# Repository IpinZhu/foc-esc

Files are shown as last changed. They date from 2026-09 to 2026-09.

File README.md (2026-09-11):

# STM32G473 三相 FOC 驱动器

这是一个基于 STM32G473RC 的实验性三相 PMSM/BLDC 电机控制平台。仓库包含驱动板设计，以及使用 Rust 2024 + Embassy 实现的电流控制型磁场定向控制（FOC）固件。

> **安全提示：** 这是一个大电流电力电子原型。固件和 PCB 尚未完成生产级电气鉴定或验证。在使用合适的实验设备和限流措施检查栅极波形、死区时间、电流采样极性、ADC 时序、故障响应、绝缘/间距和热性能之前，不要连接电机或电池。

## 当前实现

当前固件位于 [`software/firmware`](software/firmware)，目标芯片为 STM32G473RC：

- TIM1 中心对齐互补 PWM，输出引脚为 PA8/PA9/PA10 和 PB13/PB14/PB15。
- 配置的 PWM 频率：**100 kHz**。
- 配置的死区时间：在 170 MHz 定时器时钟下为 **200 ns**。
- 占空比范围：5%–95%。
- 通过 INA240A2 放大器和 0.5 mΩ 分流电阻进行三相电流反馈。
- 由定时器触发 ADC，对相电流、VBUS 和 TMP235 温度传感器进行采样。
- 支持电流 FOC、速度 FOC、开环控制、启动电流偏置校准、SVPWM、遥测和软件故障处理。
- 带版本和 CRC 的双槽 Flash 参数持久化：上电自动加载，UART `param ...` 命令和 CAN 参数帧可读取、设置、保存或恢复出厂参数。
- 电机参数自整定（Auto-Tune）：`autotune start` 一键完成 Rs/L/磁链辨识、电流环 PI 计算与阶跃验证、开环同步校验和观测器参数配置，结果保存为带 CRC 的电机参数档案，重启后自动应用。
- 编译期选择转子传感器：
  - `sensor-encoder`（默认）：TIM3 正交编码器，连接 PB4/PB5。
  - `sensor-hall`：TIM3 Hall 输入捕获，连接 PC6/PC7/PC8。
- USART3 ASCII 调试命令，连接 PB10/PB11。
- FDCAN1 classic CAN 控制和遥测，连接 PA11/PA12。

当前固件采用**纯软件保护**。本轮没有启用 COMP→DAC→TIM1-BRK 硬件过流链。软件保护包括电流阈值/去抖、相电流残差、母线欠压/过压、模型温度和传感器温度、堵转、传感器有效性以及控制超时处理。软件保护不能替代经过验证的硬件关断路径。

## 系统概览

```text
                    +-----------------------------+
  编码器 / Hall --->|                             |--> TIM1 互补 PWM
  相电流 ---------->|       STM32G473RC           |       (100 kHz, 200 ns)
  VBUS / TMP235 --->|       Rust + Embassy        |--> UCC27211 x3
  UART ------------>|       FOC 控制器            |--> 070N10NS 级三相桥
  FDCAN ----------->|                             |<-- INA240A2 x3 + 分流电阻
                    +-----------------------------+
```

固件将高速控制路径与通信路径分离。ADC 帧唤醒电机控制任务；UART 和 CAN 任务通过有界的 Embassy 同步原语交换命令和遥测数据。

## 仓库结构

| 路径 | 用途 |
|---|---|
| [`software/firmware`](software/firmware) | Rust/Embassy STM32G473RC 固件 |
| [`hardware/foc-drive/FOC2.kicad_pro`](hardware/foc-drive/FOC2.kicad_pro) | 主驱动板 KiCad 工程 |
| [`hardware/foc-drive/FOC2.kicad_sch`](hardware/foc-drive/FOC2.kicad_sch) | 主驱动板原理图 |
| [`hardware/foc-drive/FOC2.kicad_pcb`](hardware/foc-drive/FOC2.kicad_pcb) | 主驱动板 PCB 布局 |
| [`hardware/foc-expansion/foc-ex.kicad_pro`](hardware/foc-expansion/foc-ex.kicad_pro) | 扩展板 KiCad 工程 |
| [`hardware/foc-expansion/foc-ex.kicad_sch`](hardware/foc-expansion/foc-ex.kicad_sch) | 扩展板原理图 |
| [`hardware/foc-expansion/foc-ex.kicad_pcb`](hardware/foc-expansion/foc-ex.kicad_pcb) | 扩展板 PCB 布局 |
| [`foc/foc.ioc`](foc/foc.ioc) | STM32G473 CubeMX 参考配置；不是运行时固件的唯一依据 |

生成的生产文件、编辑器状态、备份文件和固件二进制文件不属于设计源文件。

## 构建和测试

以下命令均从 `software/firmware` 目录执行。由于固件的默认 Cargo 目标是 `thumbv7em-none-eabihf`，主机测试必须显式指定主机目标。

### 主机测试和 lint

```bash
cargo fmt -- --check
cargo test --target x86_64-pc-windows-msvc
cargo clippy --target x86_64-pc-windows-msvc --test fault_protection --test fault_recovery_and_diagnostics -- -D warnings
```

故障诊断集成测试位于 `software/firmware/tests/`，会使用主机仿真的 ADC 帧和转子采样，不会驱动真实 PWM 或功率级。

### Encoder 固件

```bash
cargo build --bin foc-firmware
```

### Hall 固件

```bash
cargo build --release --bin foc-firmware \
  --no-default-features --features sensor-hall
```

固件 `.cargo/config.toml` 配置了 `thumbv7em-none-eabihf`、`link.x`、`defmt.x` 以及针对 STM32G473RC 的 `probe-rs` 烧录运行器。烧录需要正确连接且获得授权的调试探针；本文档不会执行烧录操作。

## 硬件概要

主驱动设计基于以下器件和目标：

- STM32G473RC，170 MHz Cortex-M4F 电机控制 MCU。
- 三个 UCC27211 半桥栅极驱动器。
- 六个 100 V 级 N 沟道 MOSFET 位置，组成三相桥。
- 三个 INA240A2 双向电流采样放大器。
- 三个 0.5 mΩ、带 Kelvin 引线的分流电阻。
- 面向 2S–6S 电池的母线设计目标，约 5.5–25.2 V。
- VBUS 分压采样和 TMP235 模拟温度传感器。
- USART3、FDCAN1、SWD、编码器、Hall 和扩展接口。

器件额定值、热限制、自举电路尺寸、开关损耗和电流能力在实际装配电路板完成测量前都只是工程目标。详细计算和待解决问题见开发机上的本地设计说明；该文件有意不纳入共享仓库。

## 验证状态和限制

软件构建和主机测试覆盖了当前实现，但不能证明功率级运行安全。在加电连接电机之前：

1. 检查已装配电路板，确认器件安装、极性、间距、接地和 Kelvin 电流路径正确。
2. 在功率级未上电时，检查全部六路 PWM 波形、互补极性、空闲行为、MOE 关断和实测死区时间。
3. 使用低电压限流电源，验证 ADC 偏置、电流极性/比例、VBUS 比例、温度换算、转子方向和电角度零点对齐。
4. 通过受控故障注入逐项执行软件保护测试。
5. 根据 10 µs PWM 周期测量控制环最坏执行时间。
6. 在逐步增加负载的过程中测量栅极驱动器、MOSFET、分流电阻和电路板温度。
7. 在目标物理接线下确认 UART 和 CAN 行为。

因此，100 kHz 只是配置的运行目标，并不代表已证明装配后的硬件可以长期连续运行在该频率。如果时序、开关损耗、EMI、自举刷新或热测试结果不可接受，应降低集中配置中的 PWM 频率并重新进行全部验证。

## 许可证和贡献状态

固件 crate 声明采用 `MIT OR Apache-2.0` 许可证。仓库级许可证文件尚未添加。本项目目前仍处于积极的工程开发阶段；在将改动视为可发布版本之前，应结合硬件设计进行审查，并在目标电路板上完成验证。

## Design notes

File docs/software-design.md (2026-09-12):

# STM32G473 三相 FOC 固件软件设计说明

> **文档状态：** 当前实现基线  
> **适用目录：** `software/firmware`  
> **目标平台：** STM32G473RC / ARM Cortex-M4F  
> **软件栈：** Rust 2024、Embassy、`no_std`  
> **更新日期：** 2026-09-11

## 1. 文档目的

本文描述三相 PMSM/BLDC FOC 固件的软件需求、总体架构、控制流程、硬件抽象、通信协议、保护策略、配置项、测试状态和已知限制。

本文以当前 Rust 固件源码为运行时行为的主要依据：

- `software/firmware/src/`
- `software/firmware/Cargo.toml`
- `software/firmware/.cargo/config.toml`

根目录 `README.md` 和硬件 KiCad 文件用于提供系统背景与板级映射，但不能替代目标板测量。CubeMX `.ioc` 文件仅作为辅助参考，不是当前 Rust 固件配置的唯一依据。

## 2. 当前结论

当前固件已经完成主要软件功能并可为以下两种传感器配置生成 STM32G473RC ARM 固件：

- 默认 Encoder：`sensor-encoder`
- 可选 Hall：`sensor-hall`

已实现的主要能力包括：

- 100 kHz、中心对齐、三相互补 PWM；
- 200 ns 配置死区；
- 定时器触发的三相电流、母线电压和温度采样；
- 电流 FOC、速度 FOC 和开环运行模式；
- 电流偏置校准、Clarke/Park 变换、PID 和 SVPWM；
- UART 调试控制；
- Classic CAN 控制与遥测；
- 软件过流、残差、母线电压、温度、堵转、传感器和控制超时保护；
- 带版本和 CRC 的双槽 Flash 参数持久化，支持通过 UART 和 CAN 读取、设置、保存和恢复参数。
- 电机参数自整定（Auto-Tune）：一键完成 Rs/L/磁链辨识、电流环 PI 计算与阶跃验证、开环运行校验、观测器参数配置，并保存为带 CRC 的电机参数档案。

当前状态属于**可上板联调的软件工程版本**，不是经过目标板电气、热、EMI 和故障响应鉴定的生产固件。

## 3. 设计目标与非目标

### 3.1 设计目标

1. 在 STM32G473RC 上实现无堆分配的实时 FOC 控制路径。
2. 使用 TIM1 输出三相中心对齐互补 PWM。
3. 使用定时器事件触发 ADC 注入转换，使电流采样与 PWM 同步。
4. 默认以 100 kHz 执行电流环，以 1 kHz 执行速度环。
5. 编译期选择 Encoder 或 Hall 转子传感器后端。
6. 将控制核心与 STM32 外设实现分离，使核心算法能够在主机上测试。
7. 通信任务不得直接操作 PWM 或控制器硬件。
8. 故障发生时锁存故障并立即撤销桥使能请求。
9. 对命令中的非有限浮点数、错误长度和非法帧进行拒绝处理。
10. 在本轮实现中仅使用软件保护，并明确记录其能力边界。
11. 提供带版本和 CRC 的双槽 Flash 参数持久化；Flash 擦写期间暂停电流采样，且仅在桥未使能时执行。

### 3.2 当前非目标

以下内容有意不属于当前实现：

- COMP → DAC → TIM1 BRK/BKIN 硬件过流链；
- 位置无传感器估算器（自整定仅输出观测器参数，观测器本身尚未实现）；
- 自动编码器/Hall 方向和电角度零点标定；
- 弱磁、MTPA、前馈解耦和高级调制策略；
- CANopen、UAVCAN 或其他高层 CAN 协议；
- Bootloader、在线升级和安全启动；
- 生产级功能安全或电气安全认证。

## 4. 关键运行参数

| 参数 | 当前默认值 | 说明 |
|---|---:|---|
| MCU | STM32G473RC | 170 MHz Cortex-M4F |
| SYSCLK | 170 MHz | HSI / 4 × 85 / 2 |
| PWM 定时器 | TIM1 | 三路主输出及三路互补输出 |
| PWM 模式 | 中心对齐 | `CenterAlignedBothInterrupts` |
| PWM 频率 | 100 kHz | 同时作为控制器默认电流环频率 |
| PWM 周期 | 10 µs | 必须通过目标板 WCET 测量确认余量 |
| 死区 | 200 ns | 170 MHz 下 `DEAD_TIME_TICKS = 34` |
| 占空比限制 | 5%～95% | 由 SVPWM 输出约束 |
| 速度环频率 | 1 kHz | 默认每 100 个电流环周期运行一次 |
| 遥测发布频率 | 约 1 kHz | 控制任务向内部 `Watch` 发布 |
| CAN 遥测周期 | 10 ms | 每周期依次发送 3 个遥测帧 |
| UART | 115200 baud | USART3，ASCII 行协议 |
| CAN | 500 kbit/s | FDCAN1，Classic CAN 标准帧 |
| 电流校准样本数 | 1024 | 上电后保持桥关闭并计算三相 ADC 偏置 |
| 默认极对数 | 4 | 必须按实际电机修改 |
| 默认编码器 CPR | 4096 | 必须按实际编码器修改 |
| 默认电池串数 | 6S | 可在桥未运行时通过命令改为 2S～6S |
| 默认电流限制 | 50 A | 控制限制，不代表硬件连续电流能力 |
| 软件过流阈值 | 55 A | 连续 3 个采样周期后锁存 |
| 参数存储 | 2 × 4 KB Flash 双槽 | Flash 顶部 `0x0803E000`/`0x0803F000`，CRC32 加提交标记 |
| 电机参数档案 | 2 × 4 KB Flash 双槽 | `0x0803C000`/`0x0803D000`，`MTRP` 记录，自整定写入 |

## 5. 软件总体架构

### 5.1 目录结构

源码按功能分块组织：

```text
src/
├── main.rs            固件入口：时钟、引脚、外设初始化、任务启动、参数请求处理
├── lib.rs             crate 根：按功能块导出模块
├── interfaces.rs      跨模块共享类型：命令、状态、ADC 帧、遥测、协议类型
├── control/           控制核心（硬件无关，可在主机测试）
│   ├── foc_core.rs        校准、状态机、电流/速度环、保护、热模型
│   ├── foc_math.rs        Clarke/Park、SVPWM、角度处理
│   └── pid.rs             固定周期 PID
├── comm/              通信路径
│   └── comm_task.rs       UART 行协议、CAN 编解码、命令/遥测通道
├── params/            参数系统
│   ├── parameters.rs       运行参数注册表（ParameterProfileV1）
│   ├── parameter_store.rs  双槽 Flash 存储（CRC32 + 两阶段提交）
│   ├── parameter_service.rs 启动/保存状态跟踪
│   └── motor_param.rs      电机参数档案（MotorParam）
├── autotune/          电机参数自整定
│   ├── mod.rs              状态机、注入采样、PI 计算、验证
│   └── measure.rs          纯算法：拟合、离群点剔除、阶跃指标
└── bsp/               板级支持
    ├── hardware.rs         PwmBridge/RotorSensor trait（全目标）
    ├── stm32.rs            TIM1/ADC/编码器/Hall 实现（仅 ARM）
    └── flash.rs            阻塞 Flash 后端（仅 ARM）
```

### 5.2 模块职责

| 文件 | 职责 |
|---|---|
| `src/main.rs` | 编译期传感器互斥检查、RCC 配置、外设初始化、中断优先级、参数请求处理和任务启动 |
| `src/lib.rs` | 按功能块导出模块：`control`、`comm`、`params`、`autotune`、`bsp` |
| `src/interfaces.rs` | 控制模式、状态、命令、ADC 帧、转子样本、故障位、遥测、控制输出和参数协议类型 |
| `src/bsp/hardware.rs` | 定义 `PwmBridge` 和 `RotorSensor` trait |
| `src/control/foc_math.rs` | 角度归一化、正余弦近似、Clarke/Park/反 Park、SVPWM |
| `src/control/pid.rs` | 固定周期 PID、限幅、抗积分饱和、斜率限制和异常值处理 |
| `src/control/foc_core.rs` | 校准、状态机、电流环、速度环、保护、功率/热模型、遥测生成和运行参数热更新 |
| `src/params/parameters.rs` | 版本化参数注册表、范围/关系校验、payload 编解码和配置档转换 |
| `src/params/parameter_store.rs` | 双槽 Flash 记录格式、CRC32、两阶段提交和 generation 管理 |
| `src/params/parameter_service.rs` | 工作档/持久档状态、脏标记和重启需求跟踪 |
| `src/params/motor_param.rs` | 统一电机参数结构 `MotorParam`、默认值、校验、payload 编解码和配置映射 |
| `src/autotune/mod.rs` | 自整定状态机：注入采样、状态推进、PI 计算、验证与保存请求 |
| `src/autotune/measure.rs` | 纯算法：最小二乘拟合、中位数/离群点剔除、阶跃响应指标 |
| `src/bsp/flash.rs` | embassy-stm32 阻塞 Flash 后端，仅在 ARM 目标编译 |
| `src/bsp/stm32.rs` | TIM1、ADC1/2/3、ADC ISR、Encoder QEI、Hall 捕获及 STM32 引脚实现 |
| `src/comm/comm_task.rs` | UART 解析、CAN 编解码、命令队列、参数请求队列、参数响应编码及通信任务 |

### 5.3 架构原则

- **单一硬件所有者：** `motor_control_task` 独占 PWM 和转子传感器实例。
- **通信隔离：** UART/CAN 只产生 `Command`，不直接访问 PWM 或 FOC 控制器。
- **核心可测试：** `FocController` 只依赖值类型和纯算法，不依赖 STM32 寄存器。
- **静态资源：** ADC 句柄、信号、命令通道和遥测 Watch 均使用静态分配。
- **故障优先：** 任何锁存故障都会使控制输出的 `bridge_enabled` 为 `false`。
- **源码为准：** 外设、时钟和协议行为以 Rust 实现为准，不从 `.ioc` 自动生成。

## 6. 编译期配置

`Cargo.toml` 定义两个互斥特性：

```toml
[features]
default = ["sensor-encoder"]
sensor-encoder = []
sensor-hall = []
```

`main.rs` 在以下情况产生编译错误：

- 同时启用 `sensor-encoder` 和 `sensor-hall`；
- 两者均未启用。

默认构建使用 Encoder：

```bash
cargo --config "software/firmware/.cargo/config.toml" build \
  --manifest-path "software/firmware/Cargo.toml" \
  --target thumbv7em-none-eabihf --release --bin foc-firmware
```

Hall 构建使用：

```bash
cargo --config "software/firmware/.cargo/config.toml" build \
  --manifest-path "software/firmware/Cargo.toml" \
  --target thumbv7em-none-eabihf --release --bin foc-firmware \
  --no-default-features --features sensor-hall
```

## 7. 启动流程

固件启动顺序如下：

1. 配置 HSI 和 PLL，使 SYSCLK 为 170 MHz。
2. 为 FDCAN 选择 PLL1Q 内核时钟，为 ADC12/ADC345 选择 SYSCLK。
3. 初始化 STM32 外设句柄。
4. 从 Flash 双槽加载最新参数档；读取失败或无有效记录时回退到编译默认值并输出告警。
5. 将参数档应用到 `FocConfig`；Encoder CPR 和 Hall 极对数按加载后的参数初始化。
6. 配置中断优先级：
   - ADC1_2：P1；
   - TIM3：P4；
   - USART、DMA、FDCAN：P6。
7. 将 PA6 配置为下拉输入占位，但不连接到 TIM1 Break。
8. 初始化 TIM1 互补 PWM，并保持 MOE 关闭。
9. 初始化 ADC1、ADC2、ADC3 注入转换资源。
10. 根据编译特性初始化 Encoder 或 Hall 后端。
11. 初始化 USART3 和 FDCAN1。
12. 启动 UART、CAN 接收、CAN 遥测和电机控制任务。
13. 电机控制任务启用 ADC1_2 中断。
14. 控制器进入 `Calibrating`，累计默认 1024 个电流零偏样本。
15. 校准完成后进入 `Idle`，等待有效的使能命令。

在完成校准且满足运行条件前，TIM1 MOE 保持关闭。

## 8. 并发与任务模型

### 8.1 Embassy 任务

| 任务 | 触发方式 | 主要职责 |
|---|---|---|
| `motor_control_task` | 等待 ADC 帧；另有 100 µs 等待超时 | 消费命令、读取转子、执行控制器、更新 PWM、发布遥测 |
| `uart_task` | USART3 异步接收 | 解析 ASCII 行、发送命令、按需输出状态 |
| `can_receive_task` | FDCAN1 异步接收 | 验证帧格式和 DLC、解码命令、写入命令队列 |
| `can_telemetry_task` | 10 ms 定时器 | 读取最新遥测并发送三个 Classic CAN 帧 |

### 8.2 同步原语

- ADC ISR → 控制任务：单槽 `Signal<RawAdcFrame>`；
- UART/CAN → 控制任务：容量为 16 的 `Channel<Command>`；
- 控制任务 → UART/CAN：容量语义为最新值的 `Watch<Telemetry>`；
- ADC 句柄：`CriticalSectionMutex<RefCell<Option<...>>>`。

单槽 ADC 信号有意只保留最新数据。控制任务开始消费后，如果下一帧覆盖尚未消费的帧，ISR 会设置 `overrun`。控制器还会检查 ADC 序列号是否连续，因此漏帧会转化为锁存的控制超时故障。

### 8.3 实时边界

100 kHz 对应 10 µs 控制周期。当前架构要求在目标板上验证：

- ADC 注入序列能在周期预算内完成；
- ISR 读取和信号发布不会造成不可接受的抖动；
- 控制任务最坏执行时间小于周期并具有足够余量；
- UART/CAN 活动不会使线程执行器上的控制任务漏帧。

100 µs 的等待超时是无 ADC 帧时的兜底路径；正常运行中的连续性主要通过单槽覆盖标志和序列号检查检测。

## 9. PWM 设计

### 9.1 引脚映射

| 相位 | 高侧 | 低侧互补 | TIM1 通道 |
|---|---|---|---|
| A/U | PA8 | PB13 | CH1 / CH1N |
| B/V | PA9 | PB14 | CH2 / CH2N |
| C/W | PA10 | PB15 | CH3 / CH3N |

### 9.2 配置

TIM1 当前配置：

- 100 kHz；
- 中心对齐计数；
- 三路普通输出和三路互补输出；
- 34 tick 死区；
- 重复计数器为 1；
- TRGO2 来源为更新事件；
- 禁用自动输出使能；
- 禁用 BRK、BRK2 和相关输入；
- 普通输出和互补输出的空闲状态均为低；
- 初始化时写入 50% 中性比较值，但 MOE 保持关闭。

### 9.3 启停语义

`PhaseDuty::DISABLED` 的三个占空比值均为 0.5。安全关闭依赖 TIM1 MOE 被清除，而不是依赖比较值为零：

```text
运行：更新 CCR → 设置 MOE
空闲/故障：清除 MOE → 写入中性比较值
```

因此，上板时必须测量复位、初始化、空闲、故障和 MCU 异常状态下的实际栅极输出。

## 10. ADC 采样设计

### 10.1 通道映射

| ADC | 引脚 | 信号 | 注入序列 |
|---|---|---|---|
| ADC1 | PA0 | A 相电流 | Rank 1 |
| ADC1 | PA2 | VBUS | Rank 2 |
| ADC1 | PA3 | TMP235 | Rank 3 |
| ADC2 | PA1 | B 相电流 | 单通道 |
| ADC3 | PB0 | C 相电流 | 单通道 |

所有注入转换均由 TIM1 TRGO2 上升沿触发。ADC1 注入转换完成中断作为控制帧边界；ISR 随后读取三个 ADC 实例的结果。

### 10.2 原始数据帧

```rust
RawAdcFrame {
    phase_a: u16,
    phase_b: u16,
    phase_c: u16,
    bus_voltage: u16,
    ntc: u16,
    sequence: u32,
    overrun: bool,
}
```

ISR 只执行以下操作：

1. 读取注入转换结果；
2. 递增序列号；
3. 检查单槽信号是否覆盖；
4. 发布 `RawAdcFrame`。

FOC 浮点计算不在 ADC ISR 内执行。

### 10.3 电流换算

默认参数：

- ADC 参考电压：3.3 V；
- ADC 满量程：4095；
- INA240 增益：50 V/V；
- 分流电阻：0.5 mΩ。

每 ADC count 对应的电流约为：

```text
3.3 / 4095 / (50 × 0.0005) ≈ 0.03223 A/count
```

校准阶段分别平均三个相位的原始 ADC 值。运行阶段按以下方式换算：

```text
i_phase = (raw_phase - offset_phase) × amperes_per_count
```

### 10.4 VBUS 与温度换算

VBUS 默认分压为 100 kΩ / 10 kΩ：

```text
Vbus = ADC × 3.3 / 4095 × (100k + 10k) / 10k
```

TMP235 默认近似：

```text
Temperature = (Vadc - 0.5 V) / 0.01 V/°C
```

这些比例必须使用装配板和校准仪器确认。

## 11. 转子传感器设计

### 11.1 统一接口

```rust
pub trait RotorSensor {
    fn sample(&mut self, dt: f32) -> RotorSample;
}
```

返回值包含：

- 机械角度；
- 机械角速度；
- 有效标志。

电流和速度模式要求传感器有效；开环模式不要求转子传感器有效。

### 11.2 Encoder 后端

- 外设：TIM3 QEI；
- 引脚：PB4/PB5；
- 输入：上拉；
- 默认计数范围：0～4095；
- 通过计数回绕差计算机械速度；
- 通过每圈计数转换机械角度。

当前 Encoder 后端始终将成功读取的计数报告为有效。仅凭静止 QEI 计数无法区分“转子静止”和某些“编码器断线/无脉冲”情况，因此当前实现不提供完整的静止断线诊断。

### 11.3 Hall 后端

- 外设：TIM3 输入捕获；
- 引脚：PC6/PC7/PC8；
- 三通道双边沿捕获；
- 定时器频率：10 kHz；
- 识别 6 个合法 Hall 状态；
- 拒绝 `000`、`111` 和非相邻扇区跳变；
- 根据捕获间隔和跳变方向估计电角速度；
- 在合法跳变之间按估计速度插值电角度；
- 超过 0.5 s 没有跳变时将估计速度置零。

Hall 静止状态也可能在电气上保持为一个合法码。若要覆盖更多线缆故障，需要额外硬件诊断或依赖运行目标的合理性检查。

## 12. 控制器状态机

### 12.1 状态

```mermaid
stateDiagram-v2
    [*] --> Calibrating
    Calibrating --> Idle: 完成电流偏置校准
    Calibrating --> Fault: ADC overrun/序列异常
    Idle --> RunningOpenLoop: Enable(OpenLoop) 且 VBUS 合法
    Idle --> RunningCurrent: Enable(Current) 且 VBUS/传感器合法
    Idle --> RunningVelocity: Enable(Velocity) 且 VBUS/传感器合法
    RunningOpenLoop --> Idle: Disable
    RunningCurrent --> Idle: Disable
    RunningVelocity --> Idle: Disable
    RunningOpenLoop --> Fault: 保护触发
    RunningCurrent --> Fault: 保护触发
    RunningVelocity --> Fault: 保护触发
    Fault --> Idle: ClearFault 且安全且已校准
    Fault --> Calibrating: ClearFault 且安全但校准未完成
```

实际类型使用 `MotorState::Running(ControlMode)` 表示三个运行状态。

### 12.2 使能条件

只有控制器处于 `Idle` 且没有故障时才接受使能：

- VBUS 必须位于当前电池串数对应范围内；
- `Current` 和 `Velocity` 模式要求最近转子样本有效；
- `OpenLoop` 模式不要求传感器有效；
- `Idle` 不能作为有效使能模式。

### 12.3 禁用

`Disable` 会：

- 将正常运行状态切换为 `Idle`；
- 清除上次占空比请求；
- 重置电流和速度 PID 历史；
- 不清除锁存故障；
- 不会中断正在进行的偏置校准。

### 12.4 清除故障

仅在 `Fault` 状态并且满足安全条件时清除故障：

- 估算结温低于关断温度；
- 母线电压不高于当前串数上限；
- 若校准已完成，三相电流绝对值最大值小于 1 A。

校准未完成时发生故障，成功清故障后会重新开始完整偏置校准。

## 13. FOC 数据路径

```mermaid
flowchart LR
    ADC[ADC 原始帧] --> CAL[偏置与比例换算]
    CAL --> ABC[三相电流 Ia/Ib/Ic]
    ABC --> CLARKE[Clarke]
    SENSOR[Encoder/Hall] --> ANGLE[机械角到电角]
    CLARKE --> PARK[Park]
    ANGLE --> PARK
    CMD[目标 Iq/速度] --> LOOP[速度环与电流环]
    PARK --> LOOP
    LOOP --> IPARK[反 Park]
    ANGLE --> IPARK
    IPARK --> SVPWM[SVPWM 与限幅]
    VBUS[母线电压] --> LOOP
    VBUS --> SVPWM
    SVPWM --> PWM[TIM1 CCR 与 MOE]
```

### 13.1 电角度

闭环模式下：

```text
electrical_angle = normalize(
    sensor_direction × pole_pairs × mechanical_angle - electrical_zero
)
```

开环模式下：

```text
open_loop_angle += open_loop_electrical_velocity × dt
```

### 13.2 电流环

默认每个 ADC 帧执行一次，即标称 100 kHz：

- `Id` 目标固定为 0；
- `Iq` 来自电流命令或速度 PID；
- `Iq` 受温度降额后的电流上限约束；
- d/q 电压输出分别限制到母线电压的 0.5 倍；
- PID 包含输出饱和和条件积分抗饱和。

当前没有实现 d/q 电压矢量的联合圆形限幅；两个轴分别限幅，最终由 SVPWM 对相电压请求整体缩放。

### 13.3 速度环

默认每 100 个电流环周期执行一次，即 1 kHz。速度 PID 输出作为 `Iq` 目标，并受温度降额电流限制。

### 13.4 开环模式

开环模式直接指定：

- 电角速度；
- q 轴电压。

q 轴电压在使用前限制为：

```text
-0.5 × VBUS <= Uq <= 0.5 × VBUS
```

### 13.5 SVPWM

当前实现使用最小值/最大值零序注入：

1. 将 αβ 电压转换为三相电压；
2. 计算三相最大值和最小值；
3. 注入 `-0.5 × (max + min)` 共模分量；
4. 超过可用调制范围时按比例缩小；
5. 将最终占空比限制到 5%～95%。

非法母线电压、非有限 αβ 电压或非法占空比边界会返回禁用占空比。

## 14. PID 设计

`PidController` 保存：

- 配置参数；
- 积分项；
- 上一次误差；
- 上一次输出；
- 初始化标志。

更新过程：

1. 拒绝非有限误差、非有限 `dt` 或非正 `dt`；
2. 计算比例项；
3. 首次执行时不计算微分项；
4. 计算并限幅候选积分项；
5. 仅在未饱和或误差有助于退出饱和时接受积分；
6. 对总输出限幅；
7. 配置有限且为正的 `output_ramp` 时执行变化率限制；
8. 中间结果非有限时复位控制器并返回零。

默认参数：

| 控制器 | Kp | Ki | Kd | 输出限制 | 输出斜率 |
|---|---:|---:|---:|---:|---:|
| d/q 电流 PID | 0.2 | 20.0 | 0.0 | 30.0 | 无穷大，默认不限制 |
| 速度 PID | 0.4 | 2.0 | 0.0 | 50.0 | 200.0 |

这些是软件默认值，不是针对实际电机完成整定后的参数。

## 15. 保护设计

### 15.1 故障位

| 位 | 名称 | 触发条件 |
|---:|---|---|
| 0 | `OVER_CURRENT` | 任一相电流超过阈值并达到去抖计数 |
| 1 | `CURRENT_RESIDUAL` | `abs(Ia + Ib + Ic)` 超过阈值并达到去抖计数 |
| 2 | `UNDER_VOLTAGE` | 运行时 VBUS 低于当前电池串数下限 |
| 3 | `OVER_VOLTAGE` | 运行时 VBUS 高于当前电池串数上限 |
| 4 | `OVER_TEMPERATURE` | 估算结温达到关断温度 |
| 5 | `STALL` | 速度模式下持续满足堵转条件 |
| 6 | `SENSOR` | 需要传感器的模式持续收到无效样本 |
| 7 | `CONTROL_OVERRUN` | ADC 覆盖、序列不连续、控制等待超时 |
| 8 | `INVALID_COMMAND` | 已预留；当前被拒绝的协议命令不会锁存此位 |

### 15.2 默认阈值

| 项目 | 默认值 |
|---|---:|
| 软件过流阈值 | 55 A |
| 软件过流去抖 | 3 个电流采样 |
| 三相残差阈值 | 3 A |
| 残差去抖 | 20 个电流采样 |
| 单体欠压 | 3.0 V |
| 单体过压 | 4.25 V |
| 开始温度降额 | 100 °C |
| 温度关断 | 125 °C |
| 传感器无效时间 | 2 ms |
| 堵转目标速度阈值 | 10 rad/s |
| 堵转最大实测速度 | 1 rad/s |
| 堵转最小 Iq | 10 A |
| 堵转持续时间 | 0.5 s |

### 15.3 故障行为

`trip()` 会：

1. 设置对应故障位；
2. 将控制器状态切换为 `Fault`；
3. 将最后占空比重置为禁用值；
4. 使本周期输出的 `bridge_enabled` 为 `false`；
5. 由电机控制任务清除 TIM1 MOE。

故障保持锁存，必须显式发送 `ClearFault` 且满足安全条件才能恢复。

### 15.4 热模型

软件使用简化的一阶模型：

```text
P_conduction = Rds_hot × (Ia² + Ib² + Ic²)
T_target_rise = P_conduction × Rth
```

估算结温以热时间常数趋近目标温升，并取估算值与 TMP235 测量值中的较高值。100～125 °C 之间线性降低允许电流，到 125 °C 关断。

该模型不包含开关损耗、体二极管、PCB 热阻变化和风冷条件，必须通过实测修正。

### 15.5 软件保护边界

当前固件明确关闭：

- TIM1 BRK；
- TIM1 BRK2；
- Break 输入引脚；
- 自动输出使能；
- COMP/DAC 硬件阈值链。

因此，软件过流响应依赖 ADC 转换、ADC ISR、Embassy 调度和控制任务均正常运行，不能代替独立硬件快速关断。

## 16. 命令模型

`Command` 支持：

```text
Enable(mode)
Disable
ClearFault
SetIq(iq)
SetVelocity(velocity)
SetOpenLoop { electrical_velocity, q_voltage }
SetCellCount(cells)
SetElectricalZero(angle)
SetCurrentPid(config)
SetVelocityPid(config)
ReportControlOverrun
```

边界规则：

- `Iq` 被限制到正负电流上限；
- 机械速度被限制到配置最大机械速度；
- 开环电角速度被限制到配置最大开环速度；
- 非有限浮点命令被忽略或在协议解析层拒绝；
- 电池串数只接受 2～6；
- 电池串数、电角度零点和 PID 只允许在桥未请求运行时修改；
- 被拒绝的命令当前不会自动锁存 `INVALID_COMMAND`。

`SetCellCount`、`SetElectricalZero`、`SetCurrentPid` 和 `SetVelocityPid` 被控制器接受后，控制任务会把当前运行配置同步回参数工作档，保证后续 `param save` 写入 Flash 的档与实际运行配置一致。

`AutoTuneStart` 和 `AutoTuneStop` 由电机控制任务直接处理（不进入 `FocController`）：前者要求控制器处于 `Idle` 且桥未使能，后者在任何状态下立即撤销桥使能并回到 `Idle`。

## 17. UART 协议

### 17.1 物理配置

| 项目 | 配置 |
|---|---|
| 外设 | USART3 |
| TX | PB10 |
| RX | PB11 |
| 波特率 | 115200 |
| 格式 | ASCII 行，以 `\n` 结束；忽略 `\r` |
| 接收缓冲 | 128 字节 |

### 17.2 命令

| 命令 | 说明 |
|---|---|
| `enable open` | 启用开环模式 |
| `enable current` | 启用电流模式 |
| `enable velocity` | 启用速度模式 |
| `mode ...` | `enable` 的别名 |
| `disable` | 请求进入空闲并关闭桥 |
| `clear` / `clear-fault` | 请求安全清除锁存故障 |
| `iq <A>` | 设置 q 轴电流目标 |
| `velocity <rad/s>` | 设置机械角速度目标 |
| `open <electrical-rad/s> <Vq>` | 设置开环电角速度和 q 轴电压 |
| `cells <2..6>` | 设置电池串数；桥运行时不会生效 |
| `zero <rad>` | 设置电角度零点；桥运行时不会生效 |
| `current-pid <kp> <ki> <kd> <limit> <ramp>` | 设置电流 PID；所有参数必须为有限值 |
| `velocity-pid <kp> <ki> <kd> <limit> <ramp>` | 设置速度 PID；所有参数必须为有限值 |
| `param get <name>` | 读取单个参数值 |
| `param set <name> <value>` | 设置单个参数；仅在桥未使能且存储操作安全时生效 |
| `param show` | 逐行输出全部 43 个参数 |
| `param status` | 输出参数存储状态（valid/source/generation/dirty/restart-required） |
| `param save` | 把当前工作档写入 Flash 双槽 |
| `param load` | 从 Flash 重新加载最新档 |
| `param defaults` | 工作档恢复默认值；不写 Flash |
| `param factory-reset` | 强制把默认档写入 Flash 双槽 |
| `autotune start` | 启动电机参数自整定；仅当控制器 `Idle` 且桥未使能时接受 |
| `autotune stop` | 中止自整定并关闭桥 |
| `autotune status` | 输出自整定状态行（state/error/progress/辨识值） |
| `status` | 输出最新遥测摘要 |

成功接收命令返回 `ok`；解析失败返回 `error`；尚无遥测时返回 `not-ready`。

参数命令成功时按操作返回 `param <name>=<value>` 或 `ok ...` 行；失败时返回 `error <结果名>`，结果名包括 `busy`、`invalid`、`no-valid-record`、`flash-read`、`flash-erase`、`flash-program`、`verify` 等。参数名即 `ParameterId` 的名称，例如 `param set current-kp 0.35`。

超长行会整体丢弃到下一个换行符，并返回 `line-too-long`。被丢弃行的后缀不会被当作新的命令。

### 17.3 状态输出

UART 状态包含：

- ADC 序列号；
- 状态码；
- 故障位图；
- 三相电流；
- d/q 电流；
- VBUS；
- 机械速度；
- 估算结温。

## 18. Classic CAN 协议

### 18.1 总线配置

| 项目 | 配置 |
|---|---|
| 外设 | FDCAN1 |
| RX | PA11 |
| TX | PA12 |
| 比特率 | 500 kbit/s |
| 帧格式 | Classic CAN、标准 11-bit ID、数据帧 |
| 字节序 | 小端 |

自整定目前仅通过 UART 触发，未定义 CAN 帧（多节点部署前需补充节点寻址与事务语义）。

接收路径拒绝：

- Remote frame；
- CAN FD frame；
- 扩展 ID；
- 未知 ID；
- DLC 与命令定义不完全一致的帧；
- 包含 NaN 或 Infinity 的浮点命令；
- `0x106`/`0x107` 参数帧中保留字节不为 0 的帧。

### 18.2 命令帧

| ID | DLC | Payload |
|---:|---:|---|
| `0x100` | 1 | 控制码：0=Disable，1=ClearFault，2=OpenLoop，3=Current，4=Velocity |
| `0x101` | 4 | `f32` Iq 目标，单位 A |
| `0x102` | 4 | `f32` 机械速度目标，单位 rad/s |
| `0x103` | 8 | `f32` 电角速度 + `f32` q 轴电压 |
| `0x104` | 1 | 电池串数 |
| `0x105` | 4 | `f32` 电角度零点，单位 rad |
| `0x106` | 8 | 参数操作：byte0=事务号，byte1=操作（0=Status，1=Save，2=Load，3=Defaults，4=FactoryReset），byte2..7 必须为 0 |
| `0x107` | 8 | 参数访问：byte0=事务号，byte1=操作（0=Get，1=Set），byte2=参数 ID，byte3=0，byte4..7=值（Get 时必须为 0） |

参数值按类型编码为 4 字节小端：U8/I8 占 byte4，U16 占 byte4..6，F32 占 byte4..8。同一事务号重复发送相同请求会返回缓存结果；同一事务号发送不同请求会被拒绝为 `Conflict`。

### 18.3 遥测帧

#### `0x180` 状态帧

| Byte | 内容 |
|---:|---|
| 0 | 状态码 |
| 1..4 | `u32` 故障位图，小端 |
| 5 | 传感器有效标志 |
| 6..7 | ADC 序列号低 16 位，小端 |

状态码：

| 值 | 状态 |
|---:|---|
| 0 | Calibrating |
| 1 | Idle |
| 2 | Running(OpenLoop) |
| 3 | Running(Current) |
| 4 | Running(Velocity) |
| 5 | Fault |

#### `0x181` 电流帧

四个连续的小端 `i16`：

| Byte | 内容 | 比例 |
|---:|---|---:|
| 0..1 | Ia | 0.01 A/LSB |
| 2..3 | Ib | 0.01 A/LSB |
| 4..5 | Ic | 0.01 A/LSB |
| 6..7 | 平均母线电流 | 0.01 A/LSB |

#### `0x182` 运动与状态帧

| Byte | 类型 | 内容 | 比例 |
|---:|---|---|---:|
| 0..1 | `u16` | VBUS | 0.01 V/LSB |
| 2..3 | `i16` | 机械速度 | 0.01 rad/s/LSB |
| 4..5 | `u16` | 机械角度 | 0.001 rad/LSB |
| 6..7 | `i16` | 估算结温 | 0.1 °C/LSB |

发送代码以 `u16` 字节容器承载有符号速度和温度，接收端必须按 `i16` 解释对应字段。

#### `0x183` 参数操作结果帧

| Byte | 内容 |
|---:|---|
| 0 | 事务号 |
| 1 | 操作码（同 `0x106`） |
| 2 | 结果码（见下表） |
| 3 | 存储标志位：bit0=persisted_valid，bit1=dirty，bit2=restart_required，bit3=source_defaults |
| 4..8 | `u32` generation，小端 |

#### `0x184` 参数访问结果帧

| Byte | 内容 |
|---:|---|
| 0 | 事务号 |
| 1 | 操作码（0=Get，1=Set） |
| 2 | 参数 ID |
| 3 | 结果码；bit7 置位表示参数需重启后生效 |
| 4..8 | 参数值，按类型小端编码（同 `0x107`） |

参数结果码：

| 值 | 名称 | 含义 |
|---:|---|---|
| 0 | Success | 成功 |
| 1 | Unchanged | 内容未变化，未写入 Flash |
| 2 | Busy | 控制器忙或不满足安全条件 |
| 3 | Invalid | 参数 ID、类型或取值非法 |
| 4 | NoValidRecord | Flash 中无有效参数档 |
| 5..7 | FlashRead/FlashErase/FlashProgram | Flash 读/擦/写失败 |
| 8 | Verify | 写后校验失败 |
| 9 | Unknown | 未知参数 |
| 10 | QueueFull | 请求队列满 |
| 11 | Conflict | 事务号冲突 |

## 19. 遥测与诊断

内部 `Telemetry` 包含：

- 状态和故障位；
- 三相电流；
- d/q 电流和 d/q 电压；
- 三相占空比；
- 机械角度和速度；
- 传感器有效标志；
- 母线电压；
- TMP235 原始值；
- 瞬时和低通母线电流；
- 输入和输出功率估算；
- 估算结温；
- 当前 Iq 和速度目标。

母线电流和功率使用以下诊断估算：

```text
Ibus ≈ da × Ia + db × Ib + dc × Ic
Pin  ≈ VBUS × low_pass(Ibus)
Pout ≈ 1.5 × (Ud × Id + Uq × Iq)
```

这些值未经过功率计校准，不应用作计费、认证或精密效率测量。

## 20. 配置管理

参数以 `ParameterProfileV1`（schema 版本 1，payload 160 字节）为中心管理，覆盖电池串数、极对数、传感器方向、编码器 CPR、电角度零点、电流/速度 PID、采样比例、保护阈值、热模型和开环限制共 43 项。

### 20.1 Flash 存储格式

| 项目 | 值 |
|---|---|
| 存储区 | Flash 顶部双槽 A/B，各 4 KB：`0x0803E000`、`0x0803F000` |
| 记录大小 | 184 字节，剩余槽空间保持 `0xFF` |
| 记录头 | `"FOCP"` + schema 版本 `u16` + payload 长度 `u16` + generation `u32` + CRC32 `u32` |
| payload | 160 字节，从偏移 16 开始 |
| 提交标记 | 8 字节 `"COMMITV1"`，固定为最后一条写入，位于偏移 176 |

写入流程：erase 目标槽 → 按 8 字节双字写入前 176 字节 → 回读比对 → 最后写入提交标记 → 回读整条记录并解码比对。任何一步失败都会保留另一槽的旧档。启动时扫描两槽，取 CRC 与提交标记均合法且 generation 更新（含 `u32` 回绕）的记录；无有效记录时回退编译默认值，且不自动写入 Flash。

### 20.2 运行行为

- 上电加载最新档并应用到 `FocConfig`；`ParameterState` 跟踪 working/persisted 差异，产生 dirty 和 restart-required 状态。
- `pole_pairs` 和 `encoder_cpr` 为启动专用参数，修改后需重启生效；其余参数在满足安全条件时即时热更新。
- 所有 Flash 擦写仅在桥未使能、控制器 `Idle`、无故障、无过流且相电流接近零（`storage_safe`）时执行；执行期间暂停 ADC 采样触发，完成后重新同步序列号。
- UART/CAN 参数写入受同一范围与关系校验约束，非法值原样拒绝，不进入工作档。
- 遗留命令 `cells/zero/current-pid/velocity-pid` 被接受后同步进参数工作档，两条路径不会互相覆盖。

### 20.3 电机参数档案（MotorParam）

`MotorParam` 是自整定的产物与下游统一参数来源，包含定子电阻/电感、磁链、极对数、d/q 电流环与速度环 PI 增益、观测器带宽与增益、PLL 增益、HFI 参数、切换速度和电流/电压上限。

- 存储格式：`MTRP` 记录，schema 版本 1，payload 112 字节，含独立 CRC32 与 `valid_flag`；仅在自整定全部验证通过后置为已整定标记，并刷新校验和。
- 存储位置：Flash 顶部 MOTOR_A/MOTOR_B 双槽（`0x0803C000`/`0x0803D000`），与控制参数档共用同一两阶段提交逻辑（`StoredRecord` trait 泛化的双槽存储）。
- 启动应用顺序：`FocConfig::default()` → `MotorParam::apply_to_config`（仅当档案存在、已整定且校验通过）→ 控制参数档 `apply_boot`。运行参数档在重叠字段上始终优先，作为运行期微调；电机档案是整定基线。
- PI 增益域：`pid.rs` 的积分项为 `integral += ki * error * dt`（连续域），因此 `MotorParam` 保存连续域 `Ki`，自整定按 `Kp = L * wc`、`Ki = Rs * wc` 直接写入，无需乘以控制周期。

`FocConfig` 中的其余编译期常量（PWM 频率、死区、校准样本数、占空比边界等）仍以编译进固件的默认值创建，不参与持久化。

主要配置分组：

- 控制周期与速度环频率；
- 极对数、传感器方向和电角度零点；
- ADC 和电流采样比例；
- VBUS 分压；
- 校准样本数；
- 占空比、电流、速度和开环限制；
- 软件保护阈值和去抖；
- 电池串数和单体电压范围；
- 母线电流滤波；
- MOSFET/热模型参数；
- 堵转和传感器故障时间；
- TMP235 传输函数；
- 电流和速度 PID。

生产化前应确认参数默认值与实测标定一致，并保持存储格式随 schema 版本演进时的前后兼容策略。

## 21. 测试设计与当前结果

### 21.1 主机测试范围

硬件无关模块可在 Windows 主机目标上测试。当前测试覆盖：

- 正余弦近似的关键角度；
- Clarke 变换；
- Park/反 Park 往返；
- SVPWM 中性、限幅和非有限输入；
- PID 输出限幅、抗饱和、斜率和异常值；
- 三相偏置校准；
- 电流模式 PWM 输出；
- 过流、残差、欠压、过压、过温、堵转和传感器故障；
- ADC 丢帧和覆盖故障；
- 故障锁存、安全清除和重新校准；
- UART 命令解析；
- CAN 命令 DLC、浮点值和遥测字节序；
- 参数档编解码、范围/关系校验和 profile↔config 转换；
- 运行参数热更新的安全拒绝路径（运行中、非法档、校准未完成）；
- 控制采样重新同步后的序列号恢复；
- 双槽存储的交替写入、内容不变跳过、掉电中断回退、CRC 损坏回退和 generation 回绕；
- 参数服务的脏标记、重启需求和加载/保存状态迁移；
- 参数 UART 请求解析与 CAN 参数帧编解码；
- 电机参数档案编解码、校验和与双槽共存；
- 自整定纯算法（拟合、剔除、阶跃指标）；
- 自整定状态机（Rs/L 仿真辨识、PI 公式、验证通过/回退/耗尽、磁链估计、保存流程、保护与超时）；
- 自整定全流程闭环仿真（dq 电机模型，验证辨识精度与收敛）。

截至 2026-09-12：

- 单元测试：80 项通过；
- 自整定全流程仿真集成测试：3 项通过；
- 故障保护集成测试：8 项通过；
- 故障恢复和诊断集成测试：5 项通过；
- 总计：96 项通过。

### 21.2 当前构建状态

- Encoder ARM release build 和 clippy：通过；
- Hall ARM release build 和 clippy：通过；
- 格式检查：通过；
- 全量主机 `cargo clippy --lib --tests -- -D warnings`：零警告。

### 21.3 推荐验证命令

从仓库根目录执行：

```bash
cargo fmt --manifest-path "software/firmware/Cargo.toml" -- --check

cargo test \
  --manifest-path "software/firmware/Cargo.toml" \
  --lib --tests --target x86_64-pc-windows-msvc

cargo clippy \
  --manifest-path "software/firmware/Cargo.toml" \
  --lib --target x86_64-pc-windows-msvc -- -D warnings

cargo clippy \
  --manifest-path "software/firmware/Cargo.toml" \
  --target x86_64-pc-windows-msvc \
  --test fault_protection --test fault_recovery_and_diagnostics -- -D warnings
```

Encoder：

```bash
cargo --config "software/firmware/.cargo/config.toml" clippy \
  --manifest-path "software/firmware/Cargo.toml" \
  --target thumbv7em-none-eabihf --release --bin foc-firmware -- -D warnings

cargo --config "software/firmware/.cargo/config.toml" build \
  --manifest-path "software/firmware/Cargo.toml" \
  --target thumbv7em-none-eabihf --release --bin foc-firmware
```

Hall：

```bash
cargo --config "software/firmware/.cargo/config.toml" clippy \
  --manifest-path "software/firmware/Cargo.toml" \
  --target thumbv7em-none-eabihf --release --bin foc-firmware \
  --no-default-features --features sensor-hall -- -D warnings

cargo --config "software/firmware/.cargo/config.toml" build \
  --manifest-path "software/firmware/Cargo.toml" \
  --target thumbv7em-none-eabihf --release --bin foc-firmware \
  --no-default-features --features sensor-hall
```

显式传入固件 `.cargo/config.toml` 可以确保 ARM 链接时加载 `link.x` 和 `defmt.x`。

## 22. 目标板验证计划

### 22.1 烧录前

1. 对照最终原理图、PCB 和 BOM 检查全部 MCU 引脚映射。
2. 确认没有短路、反向器件或错误栅极驱动电源。
3. 断开电机和高能量电池，使用限流实验电源。
4. 确认 SWD 可以可靠连接、复位和停止 MCU。

### 22.2 PWM 与栅极驱动

1. 验证复位和空闲状态下六路栅极均关闭。
2. 检查三相主/互补 PWM 的极性和相位。
3. 测量实际 PWM 频率和 200 ns 死区。
4. 验证 `Disable`、故障和 MCU 复位时 MOE 的关断行为。
5. 检查高侧自举电压、边沿、振铃和直通风险。

### 22.3 ADC 与传感器

1. 测量 TIM1 触发到 ADC 注入转换完成的时间。
2. 检查三相采样是否在期望 PWM 位置发生。
3. 验证零电流偏置的稳定性和重复性。
4. 注入已知电流，确认三相信号极性、比例和残差。
5. 对比 VBUS 与校准电压表。
6. 对比 TMP235 与已知温度点。
7. 验证 Encoder 方向、CPR 和回绕速度。
8. 验证 Hall 六步顺序、方向、跳变间隔和插值。
9. 标定电角度零点和实际极对数。

### 22.4 控制与保护

1. 使用 DWT 周期计数器测量控制路径平均和最坏执行时间。
2. 在 UART/CAN 高负载下重复 WCET 和漏帧测试。
3. 以低电压、低电流开环开始，确认相序和转向。
4. 低增益进入电流闭环并完成电流 PID 整定。
5. 在电流环稳定后再整定速度环。
6. 受控触发每一种软件故障并测量到 MOE 关闭的延迟。
7. 逐步提高母线电压、相电流和机械负载。
8. 记录 MOSFET、驱动器、分流电阻和 PCB 温升。
9. 评估 100 kHz 下的开关损耗、EMI、自举刷新和热余量。

若 ADC 时序、控制 WCET、热损耗或 EMI 不满足要求，应将集中配置的 PWM/电流环频率降低到 40 kHz 或 20 kHz，并重新执行全部验证。

## 23. 已知限制与风险

| 风险 | 当前状态 | 后续动作 |
|---|---|---|
| 100 kHz 控制 WCET | 未在目标板测量 | 使用 DWT 测量最坏执行时间和中断抖动 |
| ADC1 包含 VBUS/TMP235 慢通道 | 周期余量未确认 | 测量 JEOS；必要时将慢通道移到低速采样路径 |
| 软件 OCP 延迟 | 设计限制 | 实测故障到 MOE 关闭时间；后续独立设计硬件 BRK |
| Encoder 静止断线 | 当前无法可靠区分 | 增加诊断输入、索引/线路监测或运动合理性策略 |
| Hall 合法静止码 | 某些断线仍有歧义 | 增加硬件信号质量检测或系统级合理性检查 |
| 默认 PID | 未按实际电机整定 | 按目标电机、电压和负载逐级整定 |
| 电角度零点 | 无自动标定 | 建立低电流标定流程并保存参数 |
| 参数持久化 | 已实现双槽 Flash + CRC + 提交标记 | 上板验证擦写时序、掉电恢复和双槽回退路径 |
| 参数访问无权限控制 | UART/CAN 均可修改并保存参数 | 部署环境确认串口/CAN 访问边界 |
| 自整定结果未上板验证 | 仿真与主机测试通过 | 低压限流复核电感/磁链辨识与 PI 验证 |
| 观测器增益约定待定 | 公式写入 MotorParam，观测器未实现 | 观测器模块落地时确认并回归 |
| 热模型简化 | 未包含完整开关损耗 | 通过热测试和功率测量修正参数 |
| 100 kHz 热/EMI | 未验证 | 实测开关波形、温度和辐射/传导噪声 |
| CAN 无节点寻址和版本协商 | 固定全局 ID | 多节点系统前定义节点 ID、协议版本和兼容策略 |
| 硬件保护未启用 | 本轮明确采用纯软件保护 | 未经独立评审不得静默启用 COMP/DAC/BRK |

## 24. 后续软件工作建议

按优先级建议：

1. 将 Hall 状态机和插值算法拆分为硬件无关组件，并增加主机单元测试。
2. 使用 DWT 增加控制循环 WCET 测量和最大值遥测。
3. 根据目标板 ADC 时序，评估将 VBUS/TMP235 改为低速采样任务。
4. 设计 Encoder/Hall 的运动合理性和过期数据诊断策略。
5. 为 UART/CAN 协议增加正式版本号、单位说明和主机端参考实现。
6. 增加板级硬件在环测试，覆盖启停、故障、通信、参数持久化和传感器边界。
7. 只有在明确提出并完成软硬件联合评审后，再实现 COMP/DAC/TIM1 BRK 硬件过流链。

## 26. 完成判据

### 26.1 当前软件迭代完成判据

- Encoder 和 Hall 两种配置均能 release 编译和 clippy；
- 主机控制与保护测试全部通过；
- UART/CAN 协议与实现一致；
- PWM、ADC、传感器和任务映射与板级设计一致；
- 软件保护能力和硬件保护缺失被明确记录。

当前实现基本满足上述代码层判据。

### 26.2 上板联调完成判据

- 六路 PWM、死区、空闲和关断行为经示波器确认；
- ADC 触发、采样时序、比例、噪声和偏置通过验证；
- Encoder/Hall 方向和电角度零点完成标定；
- 100 kHz 最坏执行时间有明确余量；
- UART/CAN 在实际接线上通过；
- 所有软件故障均完成受控注入测试；
- 低压限流条件下开环、电流环和速度环稳定运行。

当前尚无证据表明这些板级判据已经完成。

### 26.3 生产发布完成判据

除上板联调外，还至少需要：

- 最终 BOM、PCB、器件额定值和装配一致性审查；
- 连续和峰值负载热鉴定；
- 开关损耗、EMI、自举和母线瞬态测试；
- 独立、可验证的快速硬件故障关断策略；
- 参数持久化和生产标定流程；
- 长时间可靠性、异常电源和通信压力测试；
- 明确的固件版本、升级、回滚和发布流程。

当前固件不满足生产发布判据。

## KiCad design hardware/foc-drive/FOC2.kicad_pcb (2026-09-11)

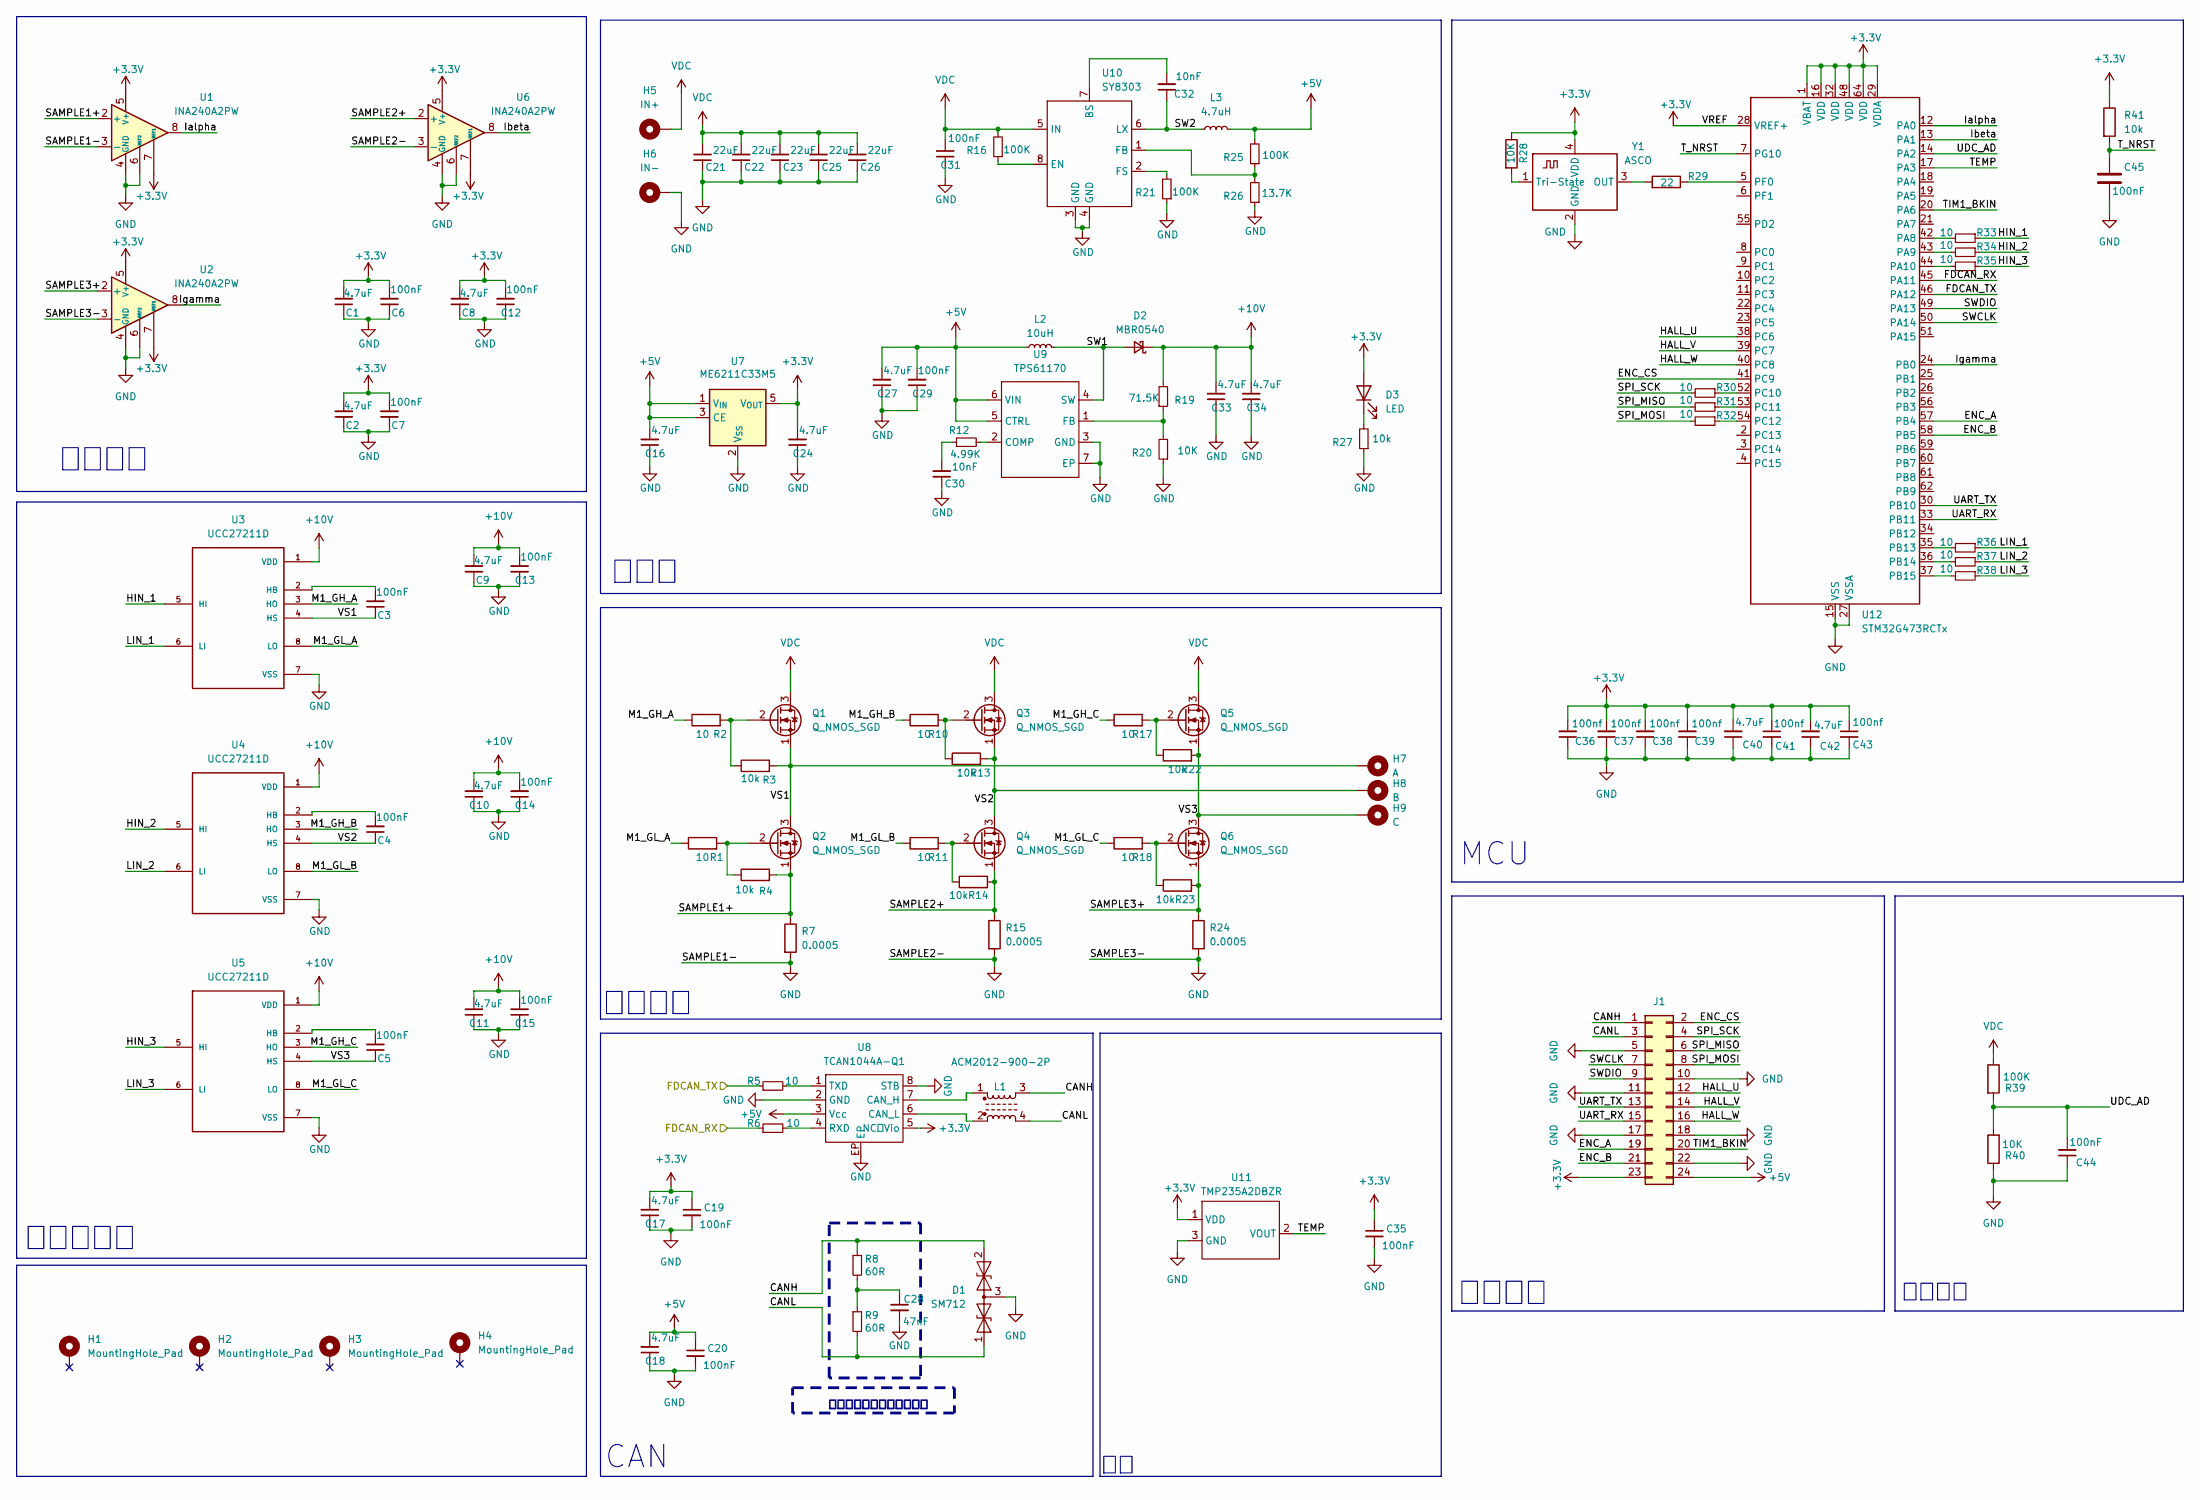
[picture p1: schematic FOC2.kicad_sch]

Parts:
C1, C2, C8, C9, C10, C11, C16, C17, C18, C24, C27, C33, C34, C40, C42: 4.7uF; C_0603_1608Metric
C3, C4, C5, C6, C7, C12, C13, C14, C15, C19, C20, C29, C31, C35, C44, C45: 100nF; C_0603_1608Metric
C21, C22, C23, C25, C26: 22uF; C_1210_3225Metric
C28: 47nF; C_0603_1608Metric
C30, C32: 10nF; C_0603_1608Metric
C36, C37, C38, C39, C41, C43: 100nf; C_0603_1608Metric
D1: SM712; SOT-23
D2: MBR0540; D_SOD-123
D3: LED; LED_0603_1608Metric
H1, H2, H3, H4: MountingHole_Pad; MountingHole_3.2mm_M3_ISO7380_Pad
H5: IN+; MountingHole_3.2mm_M3_ISO7380_Pad
H6: IN-; MountingHole_3.2mm_M3_ISO7380_Pad
H7: A; MountingHole_3.2mm_M3_ISO7380_Pad
H8: B; MountingHole_3.2mm_M3_ISO7380_Pad
H9: C; MountingHole_3.2mm_M3_ISO7380_Pad
J1: Conn_02x12_Odd_Even; PinHeader_2x12_P2.54mm_Vertical
L1: ACM2012-900-2P; ACM2012-900-2P-T001
L2: 10uH; L_Chilisin_BMRA00040420
L3: 4.7uH; L_Chilisin_BMRA00040420
Q1, Q2, Q3, Q4, Q5, Q6: Q_NMOS_SGD; VSONP-8-1EP_5x6_P1.27mm
R1, R2, R5, R6, R10, R11, R17, R18, R30, R31, R32, R33, R34, R35, R36, R37, R38: 10; R_0603_1608Metric
R3, R4, R13, R14, R22, R23, R27, R41: 10k; R_0603_1608Metric
R7, R15, R24: 0.0005; R_2512_6332Metric
R8, R9: 60R; R_0603_1608Metric
R12: 4.99K; R_0603_1608Metric
R16, R21, R25, R39: 100K; R_0603_1608Metric
R19: 71.5K; R_0603_1608Metric
R20, R28, R40: 10K; R_0603_1608Metric
R26: 13.7K; R_0603_1608Metric
R29: 22; R_0603_1608Metric
U1, U2, U6: INA240A2PW; TSSOP-8_4.4x3mm_P0.65mm
U3, U4, U5: UCC27211D; SOIC-8_3.9x4.9mm_P1.27mm; PARTREV F
U7: ME6211C33M5; SOT-23-5
U8: TCAN1044A-Q1; HVSON-8-1EP_3x3mm_P0.65mm_EP1.6x2.4mm
U9: TPS61170; WSON-6-1EP_2x2mm_P0.65mm_EP1x1.6mm_ThermalVias
U10: SY8303; TSOT-23-8
U11: TMP235A2DBZR; SOT-23
U12: STM32G473RCTx; LQFP-64_10x10mm_P0.5mm
Y1: ASCO; Crystal_SMD_2016-4Pin_2.0x1.6mm

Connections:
+3.3V: C1.2, C2.2, C6.2, C7.2, C8.2, C12.2, C17.2, C19.1, C24.2, C35.1, C36.2, C37.2, C38.2, C39.2, C40.2, C41.1, C42.2, C43.1, D3.2 (A), J1.23, R28.1, R41.1, U1.5 (V+), U1.7 (REF1), U2.5 (V+), U2.7 (REF1), U6.5 (V+), U6.7 (REF1), U7.5 (V_{OUT}), U8.5 (NC，Vio), U11.1 (VDD), U12.1 (VBAT), U12.16 (VDD), U12.28 (VREF+), U12.29 (VDDA), U12.32 (VDD), U12.48 (VDD), U12.64 (VDD), Y1.4 (VDD)
+5V: C16.2, C18.2, C20.1, C27.2, C29.2, J1.24, L2.1, L3.2, R25.2, U7.1 (V_{IN}), U7.3 (CE), U8.3 (Vcc), U9.5 (CTRL), U9.6 (VIN)
+10V: C9.2, C10.2, C11.2, C13.2, C14.2, C15.2, C33.2, C34.2, D2.1 (K), R19.2, U3.1 (VDD), U4.1 (VDD), U5.1 (VDD)
/CANH: D1.2 (A2), J1.1, L1.3, R8.1
/CANL: D1.1 (A1), J1.3, L1.4, R9.2
/ENC_A: J1.19, U12.57 (PB4)
/ENC_B: J1.21, U12.58 (PB5)
/ENC_CS: J1.2, U12.41 (PC9)
/FDCAN_RX: R6.1, U12.45 (PA11)
/FDCAN_TX: R5.1, U12.46 (PA12)
/HALL_U: J1.12, U12.38 (PC6)
/HALL_V: J1.14, U12.39 (PC7)
/HALL_W: J1.16, U12.40 (PC8)
/HIN_1: R33.1, U3.5 (HI)
/HIN_2: R34.1, U4.5 (HI)
/HIN_3: R35.1, U5.5 (HI)
/Ialpha: U1.8, U12.12 (PA0)
/Ibeta: U6.8, U12.13 (PA1)
/Igamma: U2.8, U12.24 (PB0)
/LIN_1: R36.1, U3.6 (LI)
/LIN_2: R37.1, U4.6 (LI)
/LIN_3: R38.1, U5.6 (LI)
/M1_GH_A: R2.1, U3.3 (HO)
/M1_GH_B: R10.1, U4.3 (HO)
/M1_GH_C: R17.1, U5.3 (HO)
/M1_GL_A: R1.1, U3.8 (LO)
/M1_GL_B: R11.1, U4.8 (LO)
/M1_GL_C: R18.1, U5.8 (LO)
/SAMPLE1+: Q2.1 (S), R4.2, R7.1, U1.2 (+)
/SAMPLE2+: Q4.1 (S), R14.2, R15.1, U6.2 (+)
/SAMPLE3+: Q6.1 (S), R23.2, R24.1, U2.2 (+)
/SPI_MISO: J1.6, R31.2
/SPI_MOSI: J1.8, R32.2
/SPI_SCK: J1.4, R30.2
/SW1: D2.2 (A), L2.2, U9.4 (SW)
/SW2: C32.1, L3.1, U10.6 (LX)
/SWCLK: J1.7, U12.50 (PA14)
/SWDIO: J1.9, U12.49 (PA13)
/TEMP: U11.2 (VOUT), U12.17 (PA3)
/TIM1_BKIN: J1.20, U12.20 (PA6)
/T_NRST: C45.1, R41.2, U12.7 (PG10)
/UART_RX: J1.15, U12.33 (PB11)
/UART_TX: J1.13, U12.30 (PB10)
/UDC_AD: C44.2, R39.2, R40.2, U12.14 (PA2)
/VS1: C3.1, H7.1, Q1.1 (S), Q2.3 (D), R3.2, U3.4 (HS)
/VS2: C4.1, H8.1, Q3.1 (S), Q4.3 (D), R13.2, U4.4 (HS)
/VS3: C5.1, H9.1, Q5.1 (S), Q6.3 (D), R22.2, U5.4 (HS)
GND: C1.1, C2.1, C6.1, C7.1, C8.1, C9.1, C10.1, C11.1, C12.1, C13.1, C14.1, C15.1, C16.1, C17.1, C18.1, C19.2, C20.2, C21.1, C22.1, C23.1, C24.1, C25.1, C26.1, C27.1, C28.2, C29.1, C30.1, C31.1, C33.1, C34.1, C35.2, C36.1, C37.1, C38.1, C39.1, C40.1, C41.2, C42.1, C43.2, C44.1, C45.2, D1.3 (common), H6.1, J1.5, J1.10, J1.11, J1.17, J1.18, J1.22, R7.2, R15.2, R20.1, R21.1, R24.2, R26.1, R27.1, R40.1, U1.1 (GND), U1.3 (-), U1.4 (GND), U1.6 (REF2), U2.1 (GND), U2.3 (-), U2.4 (GND), U2.6 (REF2), U3.7 (VSS), U4.7 (VSS), U5.7 (VSS), U6.1 (GND), U6.3 (-), U6.4 (GND), U6.6 (REF2), U7.2 (V_{SS}), U8.2 (GND), U8.8 (STB), U8.EP, U9.3 (GND), U9.7 (EP), U10.3 (GND), U10.4 (GND), U11.3 (GND), U12.15 (VSS), U12.27 (VSSA), U12.31 (VSS), U12.47 (VSS), U12.63 (VSS), Y1.2 (GND)
unnamed: C28.1, R8.2, R9.1
unnamed: C30.2, R12.1
unnamed: D3.1 (K), R27.2
unnamed: Q1.2 (G), R2.2, R3.1
unnamed: Q2.2 (G), R1.2, R4.1
unnamed: Q3.2 (G), R10.2, R13.1
unnamed: Q4.2 (G), R11.2, R14.1
unnamed: Q5.2 (G), R17.2, R22.1
unnamed: Q6.2 (G), R18.2, R23.1
unnamed: C3.2, U3.2 (HB)
unnamed: C4.2, U4.2 (HB)
unnamed: C5.2, U5.2 (HB)
unnamed: L1.1, U8.7 (CAN_H)
unnamed: L1.2, U8.6 (CAN_L)
unnamed: R6.2, U8.4 (RXD)
unnamed: R5.2, U8.1 (TXD)
unnamed: R12.2, U9.2 (COMP)
unnamed: R19.1, R20.2, U9.1 (FB)
unnamed: C32.2, U10.7 (BS)
unnamed: R16.1, U10.8 (EN)
unnamed: R25.1, R26.2, U10.1 (FB)
unnamed: R21.2, U10.2 (FS)
unnamed: R33.2, U12.42 (PA8)
unnamed: R34.2, U12.43 (PA9)
unnamed: R35.2, U12.44 (PA10)
unnamed: R36.2, U12.35 (PB13)
unnamed: R37.2, U12.36 (PB14)
unnamed: R38.2, U12.37 (PB15)
unnamed: R30.1, U12.52 (PC10)
unnamed: R31.1, U12.53 (PC11)
unnamed: R32.1, U12.54 (PC12)
unnamed: R29.1, U12.5 (PF0)
unnamed: R29.2, Y1.3 (OUT)
unnamed: R28.2, Y1.1 (Tri-State)
VDC: C21.2, C22.2, C23.2, C25.2, C26.2, C31.2, H5.1, Q1.3 (D), Q3.3 (D), Q5.3 (D), R16.2, R39.1, U10.5 (IN)

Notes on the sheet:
MCU
终端电阻一条总线只接两个
电压检测
主电源
通信接口
动力部分
CAN
电流采样
栅极控制器

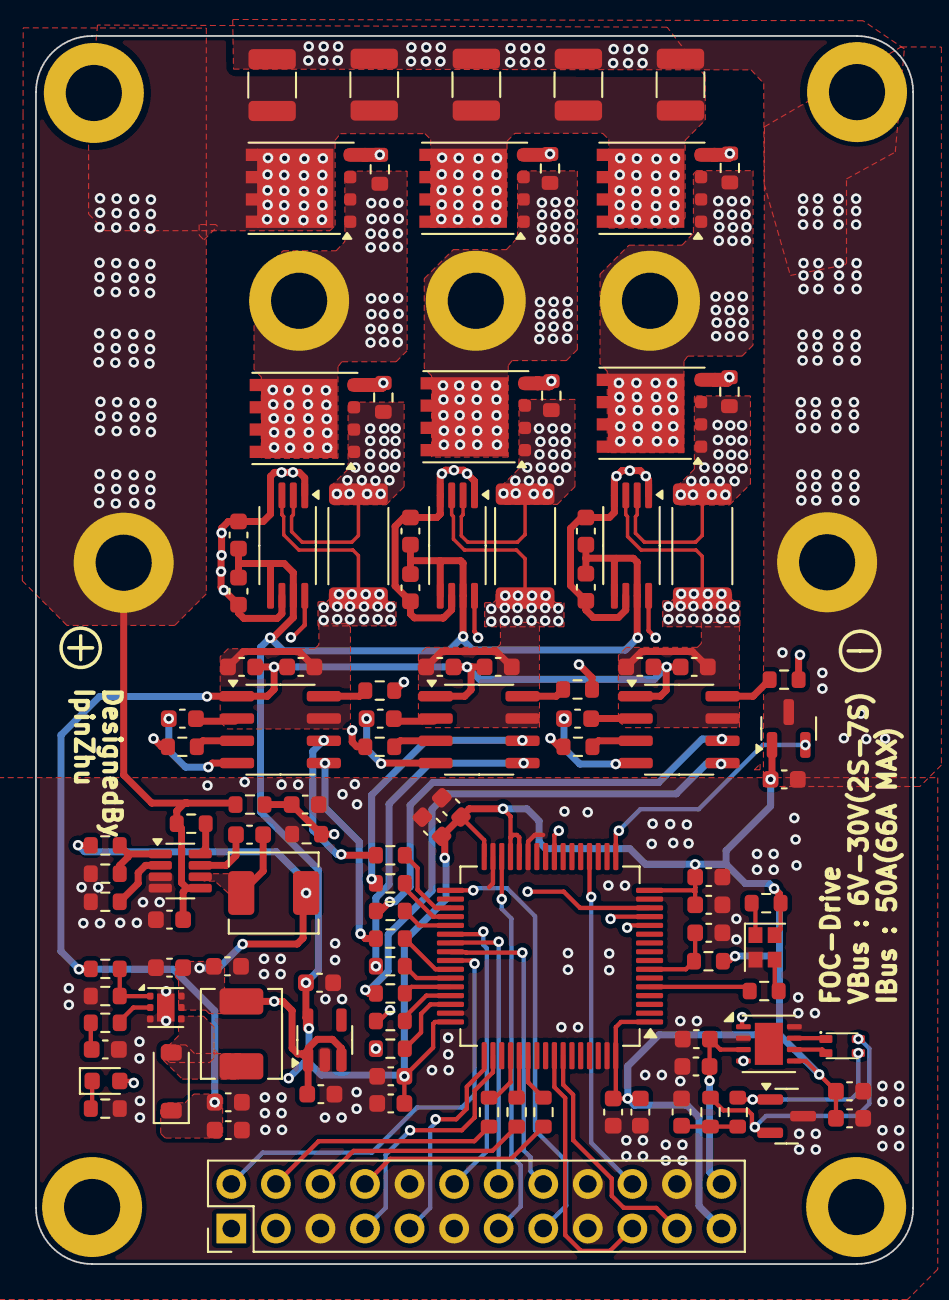
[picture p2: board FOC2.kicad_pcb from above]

Board: 4 copper layers, 50.0 x 70.0 mm, 121 parts (0 on the bottom side), 83 nets.

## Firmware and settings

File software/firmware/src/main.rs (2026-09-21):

#![cfg_attr(target_arch = "arm", no_std)]
#![cfg_attr(target_arch = "arm", no_main)]

#[cfg(target_arch = "arm")]
mod firmware {
    use defmt::{info, warn};
    use embassy_executor::Spawner;
    use embassy_futures::select::{Either, select};
    use embassy_stm32::Config;
    use embassy_stm32::can;
    use embassy_stm32::gpio::{Input, Pull};
    use embassy_stm32::interrupt;
    use embassy_stm32::interrupt::{InterruptExt, Priority};
    use embassy_stm32::usart::{Config as UartConfig, Uart};
    use embassy_time::{Duration, Timer};
    use foc_firmware::autotune::{
        AutoTuneConfig, AutoTuneController, AutoTuneState, ControlRequest,
        FastAction,
    };
    use foc_firmware::bsp::flash::Stm32FlashBackend;
    use foc_firmware::bsp::hardware::{PwmBridge, RotorSensor};
    #[cfg(all(feature = "sensor-encoder", not(feature = "sensor-hall")))]
    use foc_firmware::bsp::stm32::EncoderSensor;
    #[cfg(all(feature = "sensor-hall", not(feature = "sensor-encoder")))]
    use foc_firmware::bsp::stm32::HallSensor;
    use foc_firmware::bsp::stm32::{
        BoardIrqs, InjectedAdcResources, Tim1PwmBridge,
        enable_injected_adc_interrupt, init_injected_adcs, wait_for_adc_frame,
    };
    use foc_firmware::comm::comm_task::{
        can_receive_task, can_telemetry_task, publish_autotune_status,
        publish_parameter_response, publish_telemetry, try_receive_command,
        try_receive_parameter_request, uart_task,
    };
    use foc_firmware::comm::{ParameterTransactionCache, TransactionLookup};
    use foc_firmware::control::foc_core::{FocConfig, FocController};
    use foc_firmware::control::foc_math::PhaseDuty;
    use foc_firmware::interfaces::{
        Command, ControlMode, MotorState, ParameterAction, ParameterRequest,
        ParameterResponse, ParameterResultCode, Telemetry,
    };
    use foc_firmware::params::motor_param::{MOTOR_SLOT_LAYOUT, MotorParam};
    use foc_firmware::params::parameter_service::ParameterState;
    use foc_firmware::params::parameter_store::{
        ParameterStore, SaveOutcome, StoreError,
    };
    use foc_firmware::params::parameters::ParameterProfileV1;
    use {defmt_rtt as _, panic_probe as _};

    #[cfg(all(feature = "sensor-encoder", not(feature = "sensor-hall")))]
    type SelectedSensor = EncoderSensor<'static>;
    #[cfg(all(feature = "sensor-hall", not(feature = "sensor-encoder")))]
    type SelectedSensor = HallSensor<'static>;

    fn store_result_code<E>(error: StoreError<E>) -> ParameterResultCode {
        match error {
            | StoreError::Read(_) => ParameterResultCode::FlashRead,
            | StoreError::Erase(_) => ParameterResultCode::FlashErase,
            | StoreError::Program(_) => ParameterResultCode::FlashProgram,
            | StoreError::Verify => ParameterResultCode::Verify,
            | StoreError::Invalid => ParameterResultCode::Invalid,
        }
    }

    fn with_control_sampling_paused<T>(
        pwm: &mut Tim1PwmBridge<'static>,
        controller: &mut FocController,
        operation: impl FnOnce() -> T,
    ) -> T {
        pwm.pause_control_sampling();
        let result = operation();
        pwm.resume_control_sampling();
        controller.resynchronize_control_input();
        result
    }

    fn storage_operation_safe(
        pwm: &Tim1PwmBridge<'static>,
        controller: &FocController,
    ) -> bool {
        controller.storage_safe() && !pwm.is_enabled()
    }

    fn process_parameter_request(
        request: ParameterRequest,
        pwm: &mut Tim1PwmBridge<'static>,
        controller: &mut FocController,
        flash: &mut Stm32FlashBackend,
        parameters: &mut ParameterState,
    ) -> ParameterResponse {
        let mut result = ParameterResultCode::Success;
        let mut value = None;

        match request.action {
            | ParameterAction::Get(parameter) => {
                value = Some(parameters.get(parameter));
            },
            | ParameterAction::Status => {},
            | ParameterAction::Set(parameter, requested) => {
                value = Some(parameters.get(parameter));
                if !storage_operation_safe(pwm, controller) {
                    result = ParameterResultCode::Busy;
                } else {
                    let mut candidate = *parameters;
                    match candidate.set(parameter, requested) {
                        | Err(_) => result = ParameterResultCode::Invalid,
                        | Ok(())
                            if parameter.startup_only()
                                || controller.apply_live_profile(
                                    candidate.working(),
                                ) =>
                        {
                            *parameters = candidate;
                            value = Some(parameters.get(parameter));
                        },
                        | Ok(()) => result = ParameterResultCode::Busy,
                    }
                }
            },
            | ParameterAction::Defaults => {
                if !storage_operation_safe(pwm, controller) {
                    result = ParameterResultCode::Busy;
                } else {
                    let mut candidate = *parameters;
                    candidate.use_defaults();
                    if controller.apply_live_profile(candidate.working()) {
                        *parameters = candidate;
                    } else {
                        result = ParameterResultCode::Busy;
                    }
                }
            },
            | ParameterAction::Load => {
                if !storage_operation_safe(pwm, controller) {
                    result = ParameterResultCode::Busy;
                } else {
                    let loaded =
                        with_control_sampling_paused(pwm, controller, || {
                            let mut store = ParameterStore::new(&mut *flash);
                            store.load_latest()
                        });
                    match loaded {
                        | Ok(Some(stored)) => {
                            let mut candidate = *parameters;
                            candidate.load(stored);
                            if controller
                                .apply_live_profile(candidate.working())
                            {
                                *parameters = candidate;
                            } else {
                                result = ParameterResultCode::Busy;
                            }
                        },
                        | Ok(None) => {
                            result = ParameterResultCode::NoValidRecord
                        },
                        | Err(error) => result = store_result_code(error),
                    }
                }
            },
            | ParameterAction::Save => {
                if !storage_operation_safe(pwm, controller) {
                    result = ParameterResultCode::Busy;
                } else {
                    let outcome =
                        with_control_sampling_paused(pwm, controller, || {
                            let mut store = ParameterStore::new(&mut *flash);
                            store.save(&parameters.working())
                        });
                    match outcome {
                        | Ok(outcome) => {
                            result = if matches!(
                                outcome,
                                SaveOutcome::Unchanged { .. }
                            ) {
                                ParameterResultCode::Unchanged
                            } else {
                                ParameterResultCode::Success
                            };
                            parameters.saved(outcome);
                        },
                        | Err(error) => result = store_result_code(error),
                    }
                }
            },
            | ParameterAction::FactoryReset => {
                if !storage_operation_safe(pwm, controller) {
                    result = ParameterResultCode::Busy;
                } else {
                    let defaults = ParameterProfileV1::default();
                    let outcome =
                        with_control_sampling_paused(pwm, controller, || {
                            let mut store = ParameterStore::new(&mut *flash);
                            store.force_save(&defaults)
                        });
                    match outcome {
                        | Ok(outcome) => {
                            let mut candidate = *parameters;
                            candidate.use_defaults();
                            candidate.saved(outcome);
                            if controller
                                .apply_live_profile(candidate.working())
                            {
                                *parameters = candidate;
                            } else {
                                result = ParameterResultCode::Busy;
                            }
                        },
                        | Err(error) => result = store_result_code(error),
                    }
                }
            },
        }

        ParameterResponse {
            route: request.route,
            action: request.action,
            result,
            value,
            storage: parameters.status(),
        }
    }

    fn synchronize_legacy_parameters(
        command: Command,
        accepted: bool,
        controller: &FocController,
        parameters: &mut ParameterState,
    ) {
        if !accepted
            || !matches!(
                command,
                Command::SetCellCount(_)
                    | Command::SetElectricalZero(_)
                    | Command::SetCurrentPid(_)
                    | Command::SetVelocityPid(_)
            )
        {
            return;
        }

        let previous = parameters.working();
        let mut profile = ParameterProfileV1::from_config(
            &controller.config(),
            previous.encoder_cpr,
        );
        profile.pole_pairs = previous.pole_pairs;
        parameters.replace_working(profile);
    }

    fn apply_autotune_request(
        controller: &mut FocController,
        request: ControlRequest,
        param: &MotorParam,
    ) {
        match request {
            | ControlRequest::DisableAndResync => {
                controller.handle_command(Command::Disable);
                controller.resynchronize_control_input();
            },
            | ControlRequest::EnableCurrent => {
                controller
                    .handle_command(Command::Enable(ControlMode::Current));
            },
            | ControlRequest::EnableOpenLoop => {
                controller
                    .handle_command(Command::Enable(ControlMode::OpenLoop));
            },
            | ControlRequest::SetIq(iq) => {
                controller.handle_command(Command::SetIq(iq));
            },
            | ControlRequest::SetOpenLoop {
                electrical_velocity,
                q_voltage,
            } => {
                controller.handle_command(Command::SetOpenLoop {
                    electrical_velocity,
                    q_voltage,
                });
            },
            | ControlRequest::ApplyMotorParam => {
                if !controller.apply_motor_param(param) {
                    warn!("auto-tune parameter application rejected");
                }
            },
        }
    }

    /// Persists the commissioned motor record and the matching control
    /// profile with control sampling paused. Returns true when both
    /// records are stored.
    fn save_autotune_parameters(
        pwm: &mut Tim1PwmBridge<'static>,
        controller: &mut FocController,
        flash: &mut Stm32FlashBackend,
        parameters: &mut ParameterState,
        param: &MotorParam,
    ) -> bool {
        if !storage_operation_safe(pwm, controller) {
            warn!("auto-tune save skipped: controller not safe");
            return false;
        }
        let config = controller.config();
        with_control_sampling_paused(pwm, controller, || {
            let previous = parameters.working();
            let mut profile =
                ParameterProfileV1::from_config(&config, previous.encoder_cpr);
            profile.pole_pairs = previous.pole_pairs;
            let motor_outcome = {
                let mut store = ParameterStore::new_with_layout(
                    &mut *flash,
                    MOTOR_SLOT_LAYOUT,
                );
                store.save(param)
            };
            let profile_outcome = {
                let mut store = ParameterStore::new(&mut *flash);
                store.save(&profile)
            };
            match (motor_outcome, profile_outcome) {
                | (Ok(_), Ok(profile_outcome)) => {
                    parameters.replace_working(profile);
                    parameters.saved(profile_outcome);
                    true
                },
                | (Err(error), _) | (_, Err(error)) => {
                    warn!(
                        "auto-tune save failed: {}",
                        store_error_name(&error)
                    );
                    false
                },
            }
        })
    }

    fn store_error_name<E>(error: &StoreError<E>) -> &'static str {
        match error {
            | StoreError::Read(_) => "flash-read",
            | StoreError::Erase(_) => "flash-erase",
            | StoreError::Program(_) => "flash-program",
            | StoreError::Verify => "verify",
            | StoreError::Invalid => "invalid",
        }
    }

    #[cfg(any(
        all(feature = "sensor-encoder", not(feature = "sensor-hall")),
        all(feature = "sensor-hall", not(feature = "sensor-encoder"))
    ))]
    #[embassy_executor::task]
    async fn motor_control_task(
        mut pwm: Tim1PwmBridge<'static>,
        mut sensor: SelectedSensor,
        config: FocConfig,
        mut flash: Stm32FlashBackend,
        mut parameters: ParameterState,
        mut autotune: AutoTuneController,
    ) {
        enable_injected_adc_interrupt();
        let mut controller = FocController::new(config);
        let control_period = 1.0 / config.pwm_frequency_hz as f32;
        let telemetry_divider = (config.pwm_frequency_hz / 1_000).max(1);
        let autotune_tick_divider = (config.pwm_frequency_hz / 1_000).max(1);
        let mut autotune_frame_counter: u32 = 0;
        let mut parameter_transactions = ParameterTransactionCache::new();
        let mut control_view = Telemetry::default();

        pwm.disable();
        loop {
            while let Some(command) = try_receive_command() {
                match command {
                    | Command::AutoTuneStart => {
                        if controller.state() == MotorState::Idle
                            && !pwm.is_enabled()
                            && !autotune.is_running()
                        {
                            let seed = MotorParam::from_foc_config(
                                &controller.config(),
                            );
                            let tune_config = AutoTuneConfig::from_foc_config(
                                &controller.config(),
                            );
                            autotune = AutoTuneController::new(tune_config);
                            if autotune.start(seed) {
                                info!("auto-tune started");
                            } else {
                                warn!("auto-tune start rejected");
                            }
                        } else {
                            warn!(
                                "auto-tune start requires an idle, disabled controller"
                            );
                        }
                    },
                    | Command::AutoTuneStop => {
                        autotune.stop();
                        info!("auto-tune stop requested");
                    },
                    | _ => {
                        let accepted = controller.handle_command(command);
                        synchronize_legacy_parameters(
                            command,
                            accepted,
                            &controller,
                            &mut parameters,
                        );
                    },
                }
            }

            while let Some(envelope) = try_receive_parameter_request() {
                let request = envelope.request();
                let response = match parameter_transactions.lookup(envelope) {
                    | TransactionLookup::Replay(response) => response,
                    | TransactionLookup::Conflict => ParameterResponse {
                        route: request.route,
                        action: request.action,
                        result: ParameterResultCode::Conflict,
                        value: None,
                        storage: parameters.status(),
                    },
                    | TransactionLookup::New => process_parameter_request(
                        request,
                        &mut pwm,
                        &mut controller,
                        &mut flash,
                        &mut parameters,
                    ),
                };

                if !matches!(response.result, ParameterResultCode::Conflict) {
                    parameter_transactions.record(envelope, response);
                }
                let _ = publish_parameter_response(response);
            }

            let raw = match select(
                wait_for_adc_frame(),
                Timer::after(Duration::from_micros(100)),
            )
            .await
            {
                | Either::First(frame) => frame,
                | Either::Second(_) => {
                    controller.handle_command(Command::ReportControlOverrun);
                    pwm.disable();
                    continue;
                },
            };

            let rotor = sensor.sample(control_period);

            if autotune.is_running() {
                match autotune.fast_step(&raw) {
                    | FastAction::Inject(duty) => {
                        pwm.set_duty(duty);
                        pwm.enable();
                    },
                    | FastAction::Off => {
                        pwm.disable();
                        pwm.set_duty(PhaseDuty::DISABLED);
                    },
                    | FastAction::Delegate => {
                        let output = controller.step(raw, rotor);
                        control_view = output.telemetry;
                        if output.bridge_enabled {
                            pwm.set_duty(output.duty);
                            pwm.enable();
                        } else {
                            pwm.disable();
                            pwm.set_duty(PhaseDuty::DISABLED);
                        }
                        if raw.sequence % telemetry_divider == 0 {
                            publish_telemetry(control_view);
                        }
                    },
                }

                autotune_frame_counter += 1;
                if autotune_frame_counter >= autotune_tick_divider {
                    autotune_frame_counter = 0;
                    control_view.state = controller.state();
                    autotune.task_tick(
                        control_period * autotune_tick_divider as f32,
                        Some(&control_view),
                    );
                    while let Some(request) = autotune.pop_request() {
                        apply_autotune_request(
                            &mut controller,
                            request,
                            &autotune.motor_param(),
                        );
                    }
                    if autotune.state() == AutoTuneState::Save
                        && let Some(param) = autotune.take_save_request()
                    {
                        let saved = save_autotune_parameters(
                            &mut pwm,
                            &mut controller,
                            &mut flash,
                            &mut parameters,
                            &param,
                        );
                        autotune.notify_saved(saved);
                        if saved {
                            info!(
                                "auto-tune complete: rs={:?} ld={:?} flux={:?}",
                                param.rs, param.ld, param.flux
                            );
                        }
                    }
                    publish_autotune_status(autotune.status());
                }
            } else {
                // Drain any requests the procedure queued on completion or
                // abort (final resynchronization) before resuming normal
                // control.
                while let Some(request) = autotune.pop_request() {
                    apply_autotune_request(
                        &mut controller,
                        request,
                        &autotune.motor_param(),
                    );
                }
                let output = controller.step(raw, rotor);
                if output.bridge_enabled {
                    pwm.set_duty(output.duty);
                    pwm.enable();
                } else {
                    pwm.disable();
                    pwm.set_duty(PhaseDuty::DISABLED);
                }

                if raw.sequence % telemetry_divider == 0 {
                    publish_telemetry(output.telemetry);
                }
            }
        }
    }
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
fn main() {}

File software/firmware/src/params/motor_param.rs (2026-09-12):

use crate::control::foc_core::FocConfig;
use crate::params::parameter_store::{SlotLayout, StoredRecord};

/// Dual-slot flash layout for the motor commissioning record, located
/// directly below the control-parameter slots.
pub const MOTOR_SLOT_A_OFFSET: u32 = 0x0003_c000;
pub const MOTOR_SLOT_B_OFFSET: u32 = 0x0003_d000;
pub const MOTOR_SLOT_LAYOUT: SlotLayout = SlotLayout {
    slot_a: MOTOR_SLOT_A_OFFSET,
    slot_b: MOTOR_SLOT_B_OFFSET,
    size: crate::params::parameter_store::SLOT_SIZE,
};

/// Marks a commissioning record that completed identification and passed
/// verification. Any other value means the parameters were never
/// commissioned (or were invalidated) and must not be used to start the
/// motor.
pub const MOTOR_PARAM_VALID: u32 = 0xa55a_c33c;

pub const MOTOR_PARAM_VERSION: u32 = 1;
pub const MOTOR_PARAM_PAYLOAD_SIZE: usize = 112;
const CHECKSUM_BYTES: usize = 88;

/// Unified motor-commissioning parameters.
///
/// Every downstream consumer (FOC current/speed loops, and later the
/// sensorless observer, PLL, and HFI) takes its motor-dependent parameters
/// from this struct. PI gains are stored in the continuous domain
/// (`integrator += ki * error * dt`), matching `pid::PidController`.
///
/// Identified values are filled in by the auto-tune procedure; fields the
/// procedure does not measure (pole pairs, speed-loop gains) are seeded
/// from the running configuration and carried through unchanged.
#[derive(Clone, Copy, Debug, PartialEq)]
pub struct MotorParam {
    pub rs: f32,
    pub ld: f32,
    pub lq: f32,
    pub flux: f32,

    pub pole_pairs: u16,

    pub id_kp: f32,
    pub id_ki: f32,
    pub iq_kp: f32,
    pub iq_ki: f32,

    pub speed_kp: f32,
    pub speed_ki: f32,

    pub observer_gain: f32,
    pub observer_bandwidth: f32,

    pub pll_kp: f32,
    pub pll_ki: f32,

    pub hfi_freq: f32,
    pub hfi_voltage: f32,

    pub observer_switch_speed: f32,

    pub max_current: f32,
    pub max_voltage: f32,

    pub version: u32,
    pub checksum: u32,
    pub valid_flag: u32,
}

#[derive(Clone, Copy, Debug, PartialEq, Eq)]
pub enum MotorParamError {
    OutOfRange,
    InvalidRelationship,
    ReservedBytes,
    Checksum,
    NotCommissioned,
}

impl Default for MotorParam {
    fn default() -> Self {
        Self::from_foc_config(&FocConfig::default())
    }
}

impl MotorParam {
    /// Seeds a parameter set from the running configuration. The result is
    /// valid as a carrier but is not marked commissioned: identification
    /// and verification must complete first.
    pub fn from_foc_config(config: &FocConfig) -> Self {
        let bandwidth = 2.0 * core::f32::consts::PI * 500.0;
        let rs = 0.050_0;
        let inductance = 0.000_2;
        let flux = 0.010_0;
        Self {
            rs,
            ld: inductance,
            lq: inductance,
            flux,
            pole_pairs: u16::from(config.pole_pairs),
            id_kp: inductance * bandwidth,
            id_ki: rs * bandwidth,
            iq_kp: inductance * bandwidth,
            iq_ki: rs * bandwidth,
            speed_kp: config.velocity_pid.kp,
            speed_ki: config.velocity_pid.ki,
            observer_gain: 0.0,
            observer_bandwidth: 0.0,
            pll_kp: 0.0,
            pll_ki: 0.0,
            hfi_freq: 0.0,
            hfi_voltage: 0.0,
            observer_switch_speed: 0.0,
            max_current: 10.0_f32.min(config.current_limit),
            max_voltage: 30.0,
            version: MOTOR_PARAM_VERSION,
            checksum: 0,
            valid_flag: 0,
        }
    }

    pub const fn is_commissioned(&self) -> bool {
        self.valid_flag == MOTOR_PARAM_VALID
    }

    /// Marks the record as a completed, verified commissioning result and
    /// refreshes the payload checksum.
    pub fn mark_commissioned(&mut self) {
        self.version = MOTOR_PARAM_VERSION;
        self.valid_flag = MOTOR_PARAM_VALID;
        self.checksum = payload_checksum(&self.encode_payload());
    }

    /// Applies the motor-dependent subset to a configuration. Overlapping
    /// fields written later by the runtime control profile win over these
    /// values, so this is a baseline, not an override.
    pub fn apply_to_config(&self, config: &mut FocConfig) -> bool {
        if self.validate().is_err() {
            return false;
        }
        config.pole_pairs = self.pole_pairs.min(u16::from(u8::MAX)) as u8;
        config.current_pid.kp = self.iq_kp;
        config.current_pid.ki = self.iq_ki;
        config.velocity_pid.kp = self.speed_kp;
        config.velocity_pid.ki = self.speed_ki;
        config.current_limit =
            self.max_current.min(config.over_current_threshold);
        true
    }
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

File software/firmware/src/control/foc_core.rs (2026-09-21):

use crate::control::foc_math::{
    Dq, PhaseCurrents, PhaseDuty, clarke, inverse_park, normalize_angle, park,
    svpwm,
};
use crate::control::pid::{PidConfig, PidController};
use crate::interfaces::{
    Command, ControlMode, ControlOutput, FaultFlags, MotorState, RawAdcFrame,
    RotorSample, Telemetry,
};
use crate::params::motor_param::MotorParam;
use crate::params::parameters::ParameterProfileV1;

pub const DEFAULT_PWM_FREQUENCY_HZ: u32 = crate::timing::PWM_FREQUENCY_HZ;
pub const DEFAULT_DEAD_TIME_NS: u32 = crate::timing::DEAD_TIME_NS;

#[derive(Clone, Copy, Debug)]
pub struct FocConfig {
    pub pwm_frequency_hz: u32,
    pub speed_loop_frequency_hz: u32,
    pub pole_pairs: u8,
    pub sensor_direction: f32,
    pub electrical_zero: f32,
    pub adc_reference_voltage: f32,
    pub adc_full_scale: f32,
    pub current_sense_gain: f32,
    pub shunt_resistance: f32,
    pub bus_divider_high: f32,
    pub bus_divider_low: f32,
    pub calibration_samples: u32,
    pub minimum_duty: f32,
    pub maximum_duty: f32,
    pub current_limit: f32,
    pub over_current_threshold: f32,
    pub over_current_debounce: u16,
    pub residual_threshold: f32,
    pub residual_debounce: u16,
    pub battery_cells: u8,
    pub cell_under_voltage: f32,
    pub cell_over_voltage: f32,
    pub bus_filter_time_constant: f32,
    pub mosfet_hot_resistance: f32,
    pub thermal_resistance: f32,
    pub thermal_time_constant: f32,
    pub ambient_temperature: f32,
    pub derate_temperature: f32,
    pub shutdown_temperature: f32,
    pub stall_target_velocity: f32,
    pub stall_max_velocity: f32,
    pub stall_min_iq: f32,
    pub stall_time: f32,
    pub sensor_fault_time: f32,
    pub maximum_velocity: f32,
    pub maximum_open_loop_velocity: f32,
    pub temperature_sensor_zero_voltage: f32,
    pub temperature_sensor_volts_per_degree: f32,
    pub current_pid: PidConfig,
    pub velocity_pid: PidConfig,
}

impl Default for FocConfig {
    fn default() -> Self {
        Self {
            pwm_frequency_hz: DEFAULT_PWM_FREQUENCY_HZ,
            speed_loop_frequency_hz: 1_000,
            pole_pairs: 4,
            sensor_direction: 1.0,
            electrical_zero: 0.0,
            adc_reference_voltage: 3.3,
            adc_full_scale: 4_095.0,
            current_sense_gain: 50.0,
            shunt_resistance: 0.000_5,
            bus_divider_high: 100_000.0,
            bus_divider_low: 10_000.0,
            calibration_samples: 1_024,
            minimum_duty: 0.05,
            maximum_duty: 0.95,
            current_limit: 50.0,
            over_current_threshold: 55.0,
            over_current_debounce: 3,
            residual_threshold: 3.0,
            residual_debounce: 20,
            battery_cells: 6,
            cell_under_voltage: 3.0,
            cell_over_voltage: 4.25,
            bus_filter_time_constant: 0.02,
            mosfet_hot_resistance: 0.010,
            thermal_resistance: 2.0,
            thermal_time_constant: 10.0,
            ambient_temperature: 25.0,
            derate_temperature: 100.0,
            shutdown_temperature: 125.0,
            stall_target_velocity: 10.0,
            stall_max_velocity: 1.0,
            stall_min_iq: 10.0,
            stall_time: 0.5,
            sensor_fault_time: 0.002,
            maximum_velocity: 1_000.0,
            maximum_open_loop_velocity: 10_000.0,
            temperature_sensor_zero_voltage: 0.5,
            temperature_sensor_volts_per_degree: 0.01,
            current_pid: PidConfig::new(0.2, 20.0, 0.0, 30.0, f32::INFINITY),
            velocity_pid: PidConfig::new(0.4, 2.0, 0.0, 50.0, 200.0),
        }
    }
}

#[derive(Clone, Copy, Debug, Default)]
struct OffsetCalibrator {
    sum_a: u64,
    sum_b: u64,
    sum_c: u64,
    count: u32,
}

impl OffsetCalibrator {
    fn push(&mut self, frame: RawAdcFrame, target: u32) -> Option<[f32; 3]> {
        self.sum_a += frame.phase_a as u64;
        self.sum_b += frame.phase_b as u64;
        self.sum_c += frame.phase_c as u64;
        self.count += 1;
        if self.count < target.max(1) {
            return None;
        }
        let count = self.count as f32;
        Some([
            self.sum_a as f32 / count,
            self.sum_b as f32 / count,
            self.sum_c as f32 / count,
        ])
    }
}

pub struct FocController {
    config: FocConfig,
    state: MotorState,
    faults: FaultFlags,
    offsets: [f32; 3],
    calibrator: OffsetCalibrator,
    current_d_pid: PidController,
    current_q_pid: PidController,
    velocity_pid: PidController,
    target_iq: f32,
    target_velocity: f32,
    open_loop_velocity: f32,
    open_loop_q_voltage: f32,
    open_loop_angle: f32,
    speed_divider: u32,
    speed_counter: u32,
    over_current_count: u16,
    residual_count: u16,
    sensor_invalid_count: u32,
    stall_count: u32,
    calibration_complete: bool,
    previous_sequence: Option<u32>,
    last_duty: PhaseDuty,
    bus_current_average: f32,
    junction_temperature: f32,
    last_telemetry: Telemetry,
}
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

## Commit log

2024-01-09 修改PCB和电路图
    [FOC2-B_Cu.gbr, FOC2-B_Mask.gbr, FOC2-B_Paste.gbr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]
2025-04-21 工程重构
    [FOC2.kicad_pcb, FOC2.kicad_sch]
2025-05-15 添加驱动设计
    [FOC2.kicad_pcb, FOC2.kicad_sch]
2026-08-31 feat : redesign
    [FOC2.kicad_pcb, FOC2.kicad_sch]
2026-08-31 feat : add readme
    [FOC2.kicad_pcb, FOC2.kicad_sch]
2026-09-01 docs : 确定 FOC 参数指标与电池供电方案
    - 相电流采样:0.5mΩ/3W + INA240A2(50V/V),REF1→GND/REF2→3.3V,满量程 ±60A
    - 取消 INA226,母线电流/功率/故障诊断改软件重建
    - 输入改为 2S~6S 电池(5.5~25.2V),母线分压 47k/6.2k
    - 电源树:SY8303 Buck→5V,ME6211C33→3.3V,TPS61170→10V(VDRV)
    - 保护/风险表同步电池节数可配置、系统功率 ~1.26kW
2026-09-03 docs : 补充外设映射表并校核关键参数
2026-09-03 feat : complete sch
    [FOC2-B_Cu.gbr, FOC2-B_Mask.gbr, FOC2-B_Paste.gbr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]
2026-09-05 feat: complete pcb layout
    [FOC2.kicad_pcb, FOC2.kicad_sch]
2026-09-07 feat: add ex pcb
    [FOC2.kicad_pcb, FOC2.kicad_sch, foc-ex.kicad_pcb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]
2026-09-09 feat: add FOC firmware and fault diagnostics
    Implement the STM32G473 Embassy control path with dual sensor backends, synchronized ADC/PWM, software protections, UART/CAN telemetry, corrected VBUS divider defaults, and host integration tests for fault handling.
    [bsp_hardware.rs, comm_task.rs, fault_protection.rs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]
2026-09-09 feat: change readme
    [FOC2.kicad_pcb]
2026-09-11 feat: add flash-backed parameter persistence
    Add a versioned parameter registry (ParameterProfileV1) with dual-slot
    A/B flash storage at the top of the 256K flash, CRC32-protected records
    with a two-phase commit marker for power-loss safety, and a generation
    counter with wraparound handling.
    Expose parameter get/set/save/load/defaults/factory-reset over the
    existing UART line protocol (param ...) and four new Classic CAN frame
    IDs. Parameter requests only run flash erase/program while control
    sampling is paused and the bridge is disabled, so the 100 kHz control
    loop is never blocked by flash operations.
    Replace the memory-x feature with a custom build.rs + memory.x that
    reserves the two 4K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
    [bsp_hardware.rs, comm_task.rs, foc_core.rs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]
2026-09-11 docs: add software design doc and translate readme to Chinese
    Add docs/software-design.md describing the firmware architecture,
    control path, ADC/rotor sampling, UART/CAN protocols, software
    protection design, test results, and board-level verification plan.
    Translate README.md from English to Chinese.
2026-09-11 chore: update drive-board layout and set gerber output path
    [FOC2.kicad_pcb]
2026-09-11 test: cover controller parameter glue and clear clippy warnings
    Add controller-level tests for the flash parameter glue: live profile
    application on a safe idle controller, rejection while the bridge runs
    or the profile is invalid, sequence resynchronization after sampling
    pauses, and profile-to-config round trips including the startup-only
    pole_pairs path.
    Reference the SlotScan alias from scan() so the return type stays
    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
2026-09-11 docs: document flash parameter persistence
    Update the software design doc to the post-persistence baseline:
    describe the dual-slot record format, commit marker, boot loading and
    safety-gated erase/program flow, the param UART commands and the four
    new CAN parameter frame IDs with byte layouts, plus refreshed test
    counts and build status.
2026-09-11 feat: add one-shot motor auto-tune (commissioning)
    Add a self-contained auto-tune procedure for motor commissioning:
    Rs identification from multi-point DC injection with a least-squares
    V = Rs*I + V_offset fit (absorbing inverter dead-band effects, with a
    first-point voltage search and outlier rejection), inductance from
    short bidirectional voltage pulses fitted over the sampled i(t) ramp,
    current-loop PI from the identified parameters (Kp = L*wc, Ki = Rs*wc
    in the continuous domain used by pid.rs), a locked-rotor step
    verification with overshoot/ringing/settling metrics and a x0.75
    bandwidth rollback retry, open-loop spin with encoder synchronization
    check, flux estimation from (Vq - Rs*Iq)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
    [autotune.rs, autotune_flow.rs, comm_task.rs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]
2026-09-11 docs: document motor auto-tune commissioning
    Describe the auto-tune architecture, state machine with success/failure
    conditions, identification algorithms, PI domain semantics, MotorParam
    record format and boot application order, UART usage, current
    limitations, and refreshed test counts.
2026-09-12 chore: group firmware sources into functional modules
    Reorganize the flat src/ directory into per-function modules with no
    behavior change:
    src/control/ foc_core, foc_math, pid (hardware-independent core)
    src/comm/ comm_task (UART/CAN protocol and channels)
    src/params/ parameters registry, parameter_store, parameter_service,
    motor_param commissioning record
    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
2026-09-13 docs: add host-app requirements and architecture baseline
    Define the host application (Rust + Tauri 2) requirements: two
    transport paths (isolated USB adapter for CAN-slcan/UART, and a
    two-ESP32 2.4G bridge acting as a transparent tunnel), a unified
    transport abstraction, protocol v1 gaps that need firmware support
    (full telemetry stream, event frames, version/node-id query), functional
    and non-functional requirements with safety-focused interaction rules,
    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
2026-09-13 feat(host-app): record transport decisions and add C3 wired bridge v0
    Decisions from review: CAN adapter path deferred until the UART path is
    proven; bridge firmware will be C/C++ (Arduino-ESP32 for validation);
    the available ESP32-C3 serves as the PC-side wired bridge for proof of
    concept, with USB-Serial-JTAG caveats and UART1 pin plan documented.
    Add the M5a bridge firmware: a transparent CDC<->UART passthrough sketch
    (no protocol bytes touched, no injected traffic) that stays unchanged
    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
2026-09-13 fix(host-app): build C3 bridge with real toolchain and add UART0 variant
    Fix two compile errors surfaced by the actual ESP32 build (HWCDC is not
    a HardwareSerial: use Stream& for the PC-side reference and call begin()
    on the concrete Serial object). Add an esp32c3_uart0 environment for
    boards whose single USB port is a CH340/CP210x wired to UART0, plus a
    README section to tell the two board shapes apart and per-shape flashing
    notes. Both variants compile clean.
2026-09-13 fix(host-app): pin DTR/RTS on the bridge serial monitor
    USB-Serial-JTAG interprets certain DTR/RTS sequences as reset/download
    requests, so terminal auto-reconnect loops the chip in RTC_SW_SYS_RST
    boot banners. Pin monitor_rts/monitor_dtr to 0 in both PIO environments,
    document the symptom and remedy, and add requirement TR-B7 forbidding
    control-line toggling in the host serial layer.
2026-09-13 feat(host-app): add C3 responder mode for hardware-free link validation
    With the FOC PCB not yet fabricated, add an esp32c3_responder build
    variant that emulates the firmware's minimal ASCII protocol (status
    telemetry line with incrementing seq, param-status, ok acks) on the CDC
    port, so the PC-to-C3 link and the DTR/RTS discipline (TR-B7) can be
    validated without a motor controller attached. Record the
    hardware-free validation strategy in the requirements (C3 responder +
    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
2026-09-13 fix(host-app): responder accepts CR and CR-LF line endings
    Terminals send only CR on Enter (PIO monitor sends keystrokes raw), so
    requiring LF made the responder appear silent. Treat CR and LF as line
    terminators (empty lines produce no reply) and print a ready banner on
    boot so a silent port can be distinguished from an unresponsive one.
2026-09-13 feat(host-app): add blink bisect variant and triage doc for reset storm
    esp32c3_blink runs no serial code at all (CDC_ON_BOOT=0) so the chip can
    be observed via its LED with zero terminal interference: a steady 1 Hz
    blink exonerates the board and pins the reset storm on host control-line
    toggling (upstream esp-idf#13590 / arduino-esp32#7190), while an erratic
    or absent blink points at cable/power/USB. Restructure main.cpp into a
    per-variant setup/loop selection covering all four environments.
2026-09-13 docs(host-app): LED readout is invalid on Luat C3 core boards
    The Luat ESP32C3-CORE's two LEDs are power and network indicators not
    wired to the PIO LED_BUILTIN pin, so the triage step must use the pio
    monitor (pinned DTR/RTS) silence-vs-repeating-banner readout instead.
2026-09-21 refactor: strengthen firmware module boundaries
    [broker.rs, comm_task.rs, foc_core.rs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]
2026-10-28 feat: integrate FOC host tooling and wireless control stack
    - add the Vue/Tauri desktop app, device sessions and transport adapters
    - add the shared v2 wire protocol and firmware control-lease handling
    - replace the PlatformIO bridge with native ESP-IDF PC/motor bridges
    - capture drive-board and expansion-board design updates
    - document setup, simulation limits and pending board validation
    - exclude KiCad recovery files and preserve local editor state
    Validation: 105 firmware tests, 14 host workspace tests, 7 wire tests,
    bridge C++ interface tests, frontend production build, and encoder/Hall
    ARM release builds and Clippy checks passed. No board validation performed.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
2026-10-29 feat: simulate sensored FOC and validate auto-tune parameters
    Add an independent PMSM host simulation with deterministic timing, phase-current sampling, control scenarios, and commissioning accuracy checks. Allow bounded rotor acceleration before auto-tune sync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
    Validation: 107 firmware tests and 24 simulator tests passed; simulator and both ARM sensor configurations passed Clippy, and both ARM release builds linked. No hardware validation performed.
